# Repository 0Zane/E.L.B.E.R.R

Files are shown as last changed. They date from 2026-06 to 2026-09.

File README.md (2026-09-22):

<div align="center">
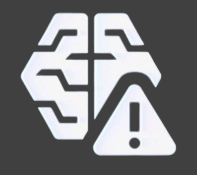
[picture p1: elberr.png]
E.L.B.E.R.R. icon
  

  <h1>E.L.B.E.R.R.</h1>

  <p>
    A fanmade animatronic robot powered by local AI, embedded control systems,
    and custom hardware.
  </p>

  <p>
    <a href="https://github.com/0Zane/E.L.B.E.R.R./stargazers">
      
    </a>
    <a href="https://github.com/0Zane/E.L.B.E.R.R./issues">
      
    </a>
    
    
    
    
  </p>
</div>

---

## Overview

**E.L.B.E.R.R.** is a fanmade animatronic project inspired by the robot featured
in the animations from [LIGHTS ARE OFF](https://www.youtube.com/@LIGHTSAREOFF).

The goal of this project is to recreate the character as a physical animatronic
robot using a custom local AI system, embedded motor control, sensors, and
purpose-built hardware. E.L.B.E.R.R. is designed as a self-contained robot that
can process information locally, control its own actuators, and respond through
real-time embedded systems.

> This is an unofficial fan project. It is not affiliated with, endorsed by, or
> produced by LIGHTS ARE OFF.

<div align="center">
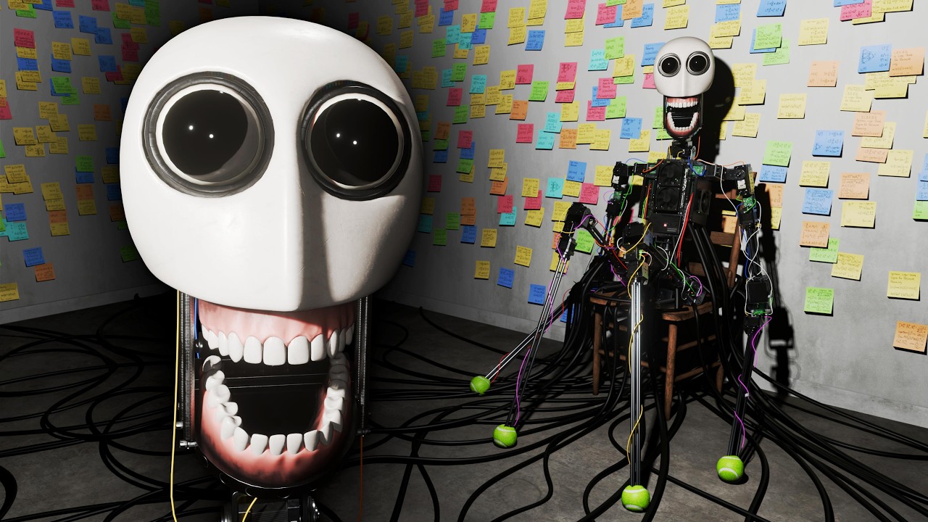
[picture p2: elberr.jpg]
E.L.B.E.R.R. animatronic reference
  
  <br />
  <sub>Reference image of the robot from the original animation.</sub>
</div>

---

## Built Robot Gallery

A few photos from the assembled robot, scaled for cleaner viewing in the repository.

<div align="center">
  <table>
    <tr>
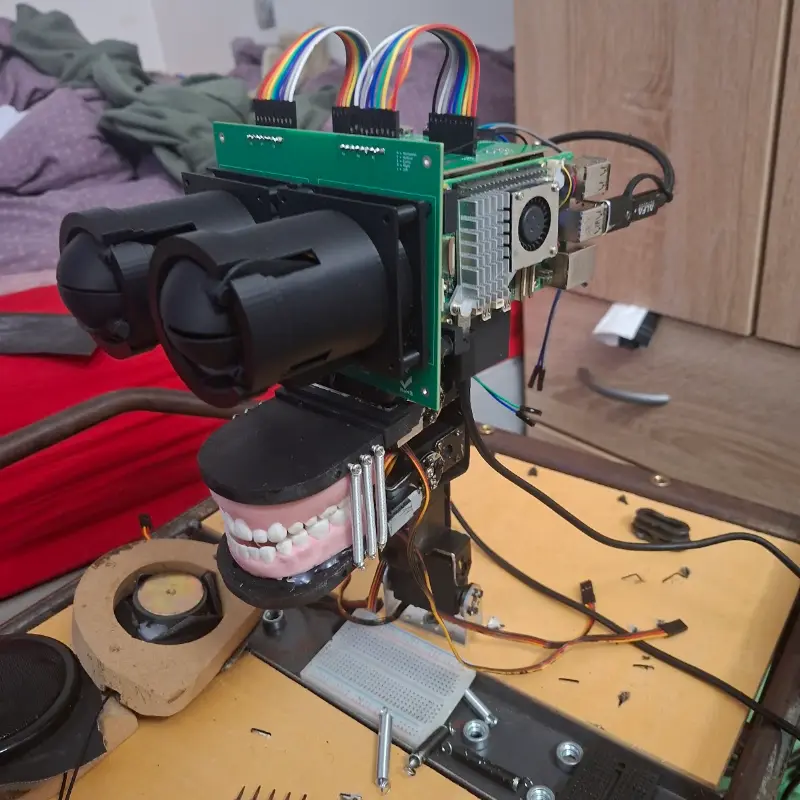
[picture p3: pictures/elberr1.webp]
E.L.B.E.R.R. assembled robot front view
      <td align="center"></td>
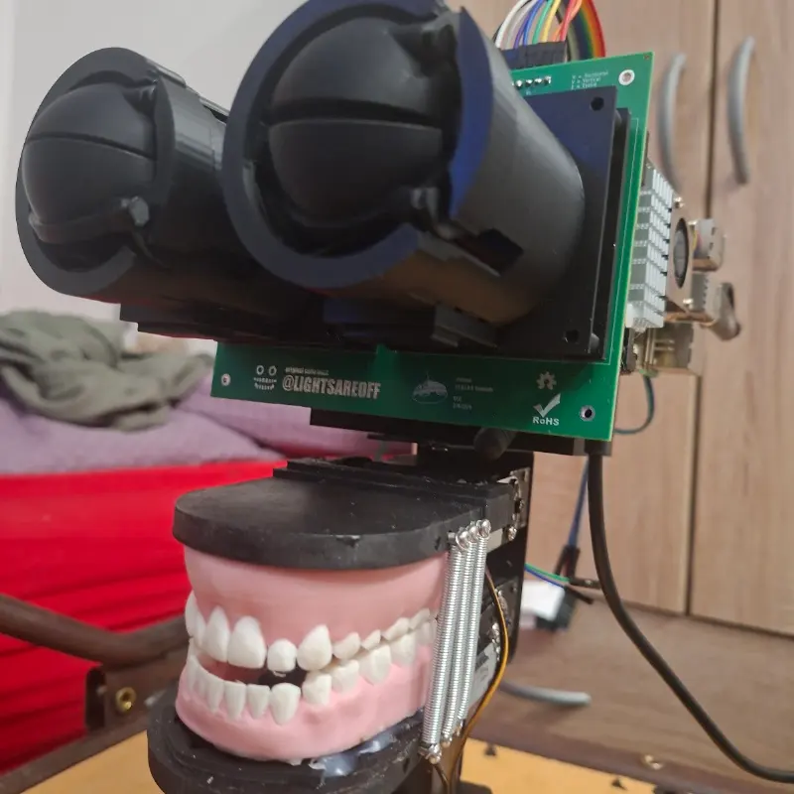
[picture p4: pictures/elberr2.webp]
E.L.B.E.R.R. assembled robot side view
      <td align="center"></td>
    </tr>
    <tr>
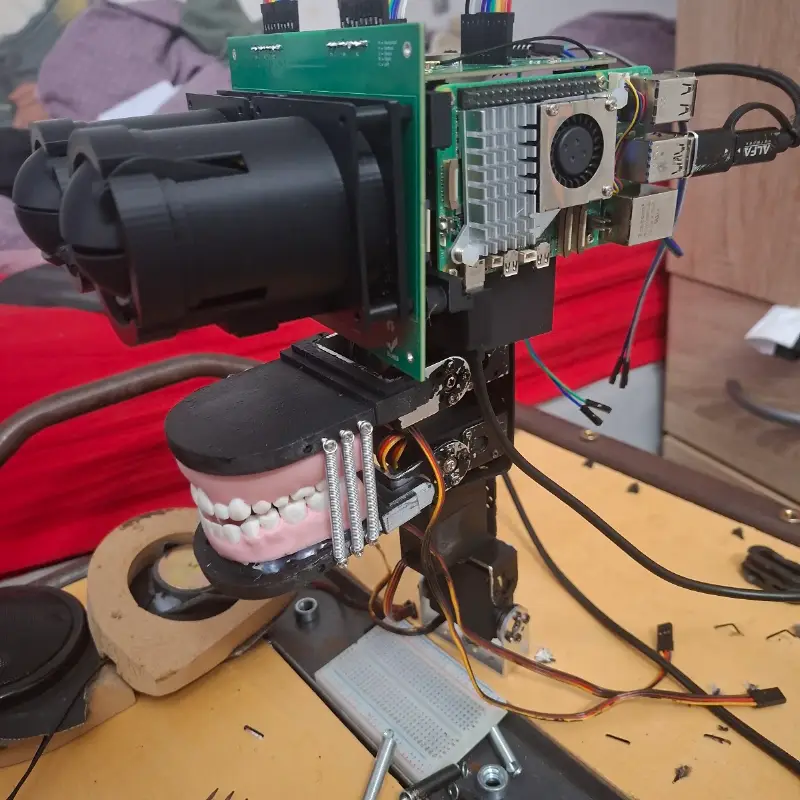
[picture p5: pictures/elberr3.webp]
E.L.B.E.R.R. assembled robot face detail
      <td align="center"></td>
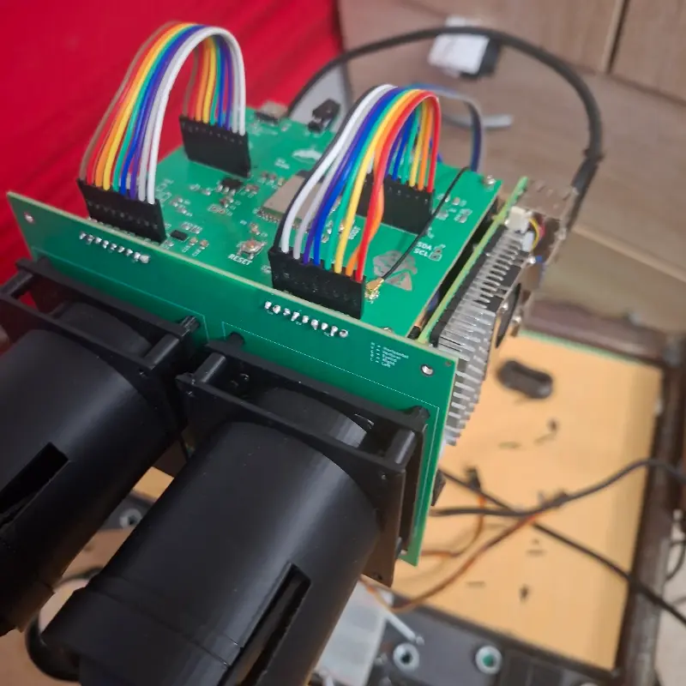
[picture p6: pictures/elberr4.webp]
E.L.B.E.R.R. assembled robot close-up
      <td align="center"></td>
    </tr>
  </table>
</div>

---

# Architecture

## Core Concept

E.L.B.E.R.R. is built around a three-processor architecture:

* A **Raspberry Pi 5** acts as the primary computer, running the local AI system, behavior engine, perception, and overall robot coordination.
* An **ESP32-S3** serves as the communication and sensing processor, handling environmental sensors, wireless connectivity, and RF communication.
* An **STM32** microcontroller is dedicated to real-time servo and actuator control, ensuring smooth, deterministic motion and reliable animatronic performance.

This separation allows each processor to focus on a specific task while keeping motion control isolated from higher-level software.

The Raspberry Pi 5, ESP32-S3, and STM32 communicate with one another over UART.

```mermaid
flowchart LR
  Camera[Camera] --> Pi[Raspberry Pi 5]
  Mic[Microphone] --> Pi
  Other[Embedded Sensors] --> ESP

  Pi <-->|UART| ESP[ESP32-S3]

  Pi --> AI[Local AI System]
  AI --> Behavior[Behavior Engine]

  Pi <-->|UART| STM[STM32]
  STM --> Servos[Servos]
  STM --> Actuators[Animatronic Actuators]
```

---

## Hardware Architecture

| Subsystem | Component | Purpose |
| --- | --- | --- |
| Main computer | Raspberry Pi 5 | Local AI, behavior logic, planning, vision processing, networking, and system orchestration |
| Sensor & RF controller | ESP32-S3 | Environmental sensors, wireless communication, RF capabilities, and data collection |
| Motion controller | STM32 | Real-time servo control, actuator control, deterministic timing, and motion safety |
| Mechanical system | Animatronic frame | Physical movement, expression, and character presence |
| Sensors | Cameras, microphones, IMUs, and embedded sensors | Environmental input and interaction data |
| PCB design | KiCad | Custom circuit design, wiring organization, and hardware integration |
| Firmware | C++ | Embedded software for STM32 and ESP32-S3 |

---

## Raspberry Pi 5

The Raspberry Pi 5 is the central computer of E.L.B.E.R.R.

Its responsibilities include:

* Running the local AI system
* Managing high-level robot behavior
* Processing camera, microphone, and perception data
* Coordinating communication between all processors
* Handling networking, logging, and debugging
* Making behavioral decisions before sending motion commands to the STM32

The Pi is responsible for what the robot **thinks**.

---

## ESP32-S3

The ESP32-S3 is dedicated to sensing and wireless communication.

Its responsibilities include:

* Reading environmental sensors
* Monitoring digital and analog inputs
* Handling RF and wireless communication
* Forwarding sensor information to the Raspberry Pi 5
* Providing low-power peripheral management

The ESP32-S3 is responsible for what the robot **perceives** and how it communicates with external devices.

---

## STM32

The STM32 is dedicated to real-time motion control.

Its responsibilities include:

* Driving servos and animatronic actuators
* Generating precise PWM outputs
* Executing smooth motion profiles
* Enforcing movement limits
* Monitoring actuator timing
* Executing commands received from the Raspberry Pi 5

The STM32 is responsible for how the robot **moves**.

---

## Hardware Schematics

The design files in the repository include the core hardware schematics and module layouts for the robot control system.

<div align="center">
  <table>
    <tr>
      <td align="center"><h3>ESP modules</h3>E.L.B.E.R.R. hardware module overview</td>
      <td align="center"><h3>ESP32-S3 board</h3>ESP32-S3 schematic</td>
      <td align="center"><h3>Eye module</h3>Eye module schematic</td>
    </tr>
  </table>
</div>

---

## Project Structure

```text
E.L.B.E.R.R/
|-- 3dmodels/
|-- esp32-firmware/
|   |-- include/
|   |-- lib/
|   |-- src/
|   |-- test/
|   `-- platformio.ini
|-- hardware/
|   |-- README.md
|   |-- esp/
|   |   |-- esp.kicad_pro
|   |   |-- esp.kicad_sch
|   |   |-- esp.kicad_pcb
|   |   |-- bom.csv
|   |   |-- production/
|   |   `-- esp-backups/
|   |-- eyes/
|   |   |-- eyes.kicad_pro
|   |   |-- eyes.kicad_sch
|   |   |-- eyes.kicad_pcb
|   |   |-- bom.csv
|   |   |-- production/
|   |   `-- eyes-backups/
|   |-- stm/
|   |   |-- stm.kicad_pro
|   |   |-- stm.kicad_sch
|   |   |-- stm.kicad_pcb
|   |   |-- stm-backups/
|   |   `-- ...
|   |-- esp.svg
|   |-- eyes.svg
|   `-- modules.svg
|-- pictures/
|   |-- elberr1.webp
|   |-- elberr2.webp
|   |-- elberr3.webp
|   `-- elberr4.webp
|-- software/
|   |-- README.md
|   |-- Modelfile
|   |-- boot.py
|   |-- llm.py
|   |-- main.py
|   |-- requirements.txt
|   |-- stt.py
|   |-- tts.py
|   `-- memory/
|-- stm32-firmware/
|   |-- Core/
|   |-- Drivers/
|   |-- EWARM/
|   |-- stm32-firmware.ioc
|   `-- ...
|-- index.html
|-- elberr.jpg
|-- elberr.png
|-- README.md
|-- LICENSE
`-- .gitignore (if present)
```

---

## Technologies

| Area | Technology |
| --- | --- |
| Main compute | Raspberry Pi 5 |
| Sensor processor  | ESP32-S3 |
| Motion controller | STM32 |
| Firmware | C++ |
| PCB design | KiCad |
| 3D modeling | Fusion 360 |
| AI | Local custom AI system |
| Architecture | Distributed embedded system |

---

## Inspiration

This project is inspired by the robot created in the animations from
[LIGHTS ARE OFF](https://www.youtube.com/@LIGHTSAREOFF).

E.L.B.E.R.R. is a fanmade physical interpretation of that concept, built as a
personal robotics, AI, and embedded systems project.

---

## License

This project is licensed under the **MIT License**.

See the [LICENSE](./LICENSE) file for details.

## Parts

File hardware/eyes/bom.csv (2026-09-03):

Reference | Qty | Value | DNP | Exclude from BOM | Exclude from Board | Footprint | Datasheet
C1,C2 | 2 | 0.1uF |  |  |  | Capacitor_SMD:C_0805_2012Metric
C7 | 1 | 100uF |  |  |  | Capacitor_THT:CP_Radial_D8.0mm_P3.50mm
J1,J2,J3,J4 | 4 | Conn_01x09_Pin |  |  |  | Connector_PinHeader_2.54mm:PinHeader_1x09_P2.54mm_Vertical
J5 | 1 | Barrel_Jack |  |  |  | Connector_BarrelJack:BarrelJack_Horizontal
J8,J9 | 2 | Conn_01x22 |  |  |  | Connector_FFC-FPC:Amphenol_F32Q-1A7x1-11022_1x22-1MP_P0.5mm_Horizontal

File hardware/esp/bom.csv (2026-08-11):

Reference | Value | Footprint | Qty | DNP
C1,C3,C7,C9 | 10uF | Capacitor_SMD:C_0805_2012Metric | 4
C2,C4,C6,C10,C15,C23,C24,C25 | 0.1uF | Capacitor_SMD:C_0805_2012Metric | 8
C5,C11,C18 | 4.7uF | Capacitor_SMD:C_0805_2012Metric | 3
C8 | 0.1µF | Capacitor_SMD:C_0805_2012Metric | 1
C12 | 10nF | Capacitor_SMD:C_0603_1608Metric | 1
C13 | 1nF | Capacitor_SMD:C_0603_1608Metric | 1
C14 | 33nF | Capacitor_SMD:C_0603_1608Metric | 1
C16,C19 | 22pF | Capacitor_SMD:C_0603_1608Metric | 2
C17 | 2.2nF | Capacitor_SMD:C_0805_2012Metric | 1
C20 | 4.7pF | Capacitor_SMD:C_0805_2012Metric | 1
C21 | 1.5pF | Capacitor_SMD:C_0603_1608Metric | 1
C22 | 1pF | Capacitor_SMD:C_0603_1608Metric | 1
D1,D2,D3,D10,D11,D12 | D_TVS | Diode_SMD:D_SOD-123 | 6
D4,D5,D6,D7,D8,D9 | LED | LED_SMD:LED_0603_1608Metric | 6
J1,J4,J9 | Conn_01x02 | Connector_PinHeader_2.54mm:PinHeader_1x02_P2.54mm_Vertical | 3
J2,J3 | USB_C_Receptacle_USB2.0_16P | Connector_USB:USB_C_Receptacle_HCTL_HC-TYPE-C-16P-01A | 2
J5 | Conn_Coaxial | Connector_Coaxial:U.FL_Molex_MCRF_73412-0110_Vertical | 1
J6,J8 | Conn_01x09_Pin | Connector_PinHeader_2.54mm:PinHeader_1x09_P2.54mm_Vertical | 2
J7 | Conn_01x06_Pin | Connector_PinHeader_2.54mm:PinHeader_1x06_P2.54mm_Vertical | 1
L1 | 8.2nH | Inductor_SMD:L_0603_1608Metric | 1
L2 | 3.9nH | Inductor_SMD:L_0603_1608Metric | 1
L3 | 2.7nH | Inductor_SMD:L_0603_1608Metric | 1
R1,R2,R5,R6 | 5.1k | Resistor_SMD:R_0805_2012Metric | 4
R3,R4 | 22R | Resistor_SMD:R_0805_2012Metric | 2
R7,R8,R11,R12,R13,R14,R19 | 1k | Resistor_SMD:R_0805_2012Metric | 7
R9,R24 | 10k | Resistor_SMD:R_0805_2012Metric | 2
R10 | 10K | Resistor_SMD:R_0805_2012Metric | 1
R15,R16,R20,R21 | 4.7k | Resistor_SMD:R_0805_2012Metric | 4
R17 | 22K | Resistor_SMD:R_0603_1608Metric | 1
R18 | 1M | Resistor_SMD:R_0805_2012Metric | 1
R22 | 47.5k | Resistor_SMD:R_0805_2012Metric | 1
R23 | 22.1k | Resistor_SMD:R_0805_2012Metric | 1
SW1 | RESET | Button_Switch_SMD:SW_SPST_SKQG_WithStem | 1
SW2 | BOOT | Button_Switch_SMD:SW_SPST_SKQG_WithStem | 1
U1 | AMS1117-3.3 | Package_TO_SOT_SMD:SOT-223-3_TabPin2 | 1
U2 | CP2102N-Axx-xQFN20 | Package_DFN_QFN:SiliconLabs_QFN-20-1EP_3x3mm_P0.5mm_EP1.8x1.8mm | 1
U3 | ESP32-S3-WROOM-1 | RF_Module:ESP32-S3-WROOM-1 | 1
U4 | VL53L0X | VL53L0X:SENSOR_VL53L0X | 1
U5 | NRF24L01 | Package_DFN_QFN:QFN-20-1EP_4x4mm_P0.5mm_EP2.5x2.5mm | 1
U6 | BME280 | Package_LGA:Bosch_LGA-8_2.5x2.5mm_P0.65mm_ClockwisePinNumbering | 1
Y1 | 16MHz | Crystal:Crystal_SMD_3225-4Pin_3.2x2.5mm | 1

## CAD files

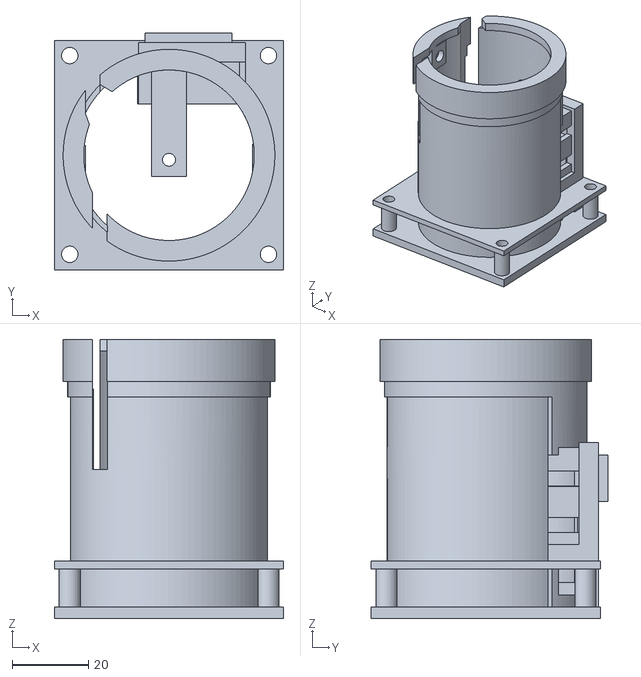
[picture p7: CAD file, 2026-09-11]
3dmodels/eyesupport.stl
60.0 x 62.0 x 73.0

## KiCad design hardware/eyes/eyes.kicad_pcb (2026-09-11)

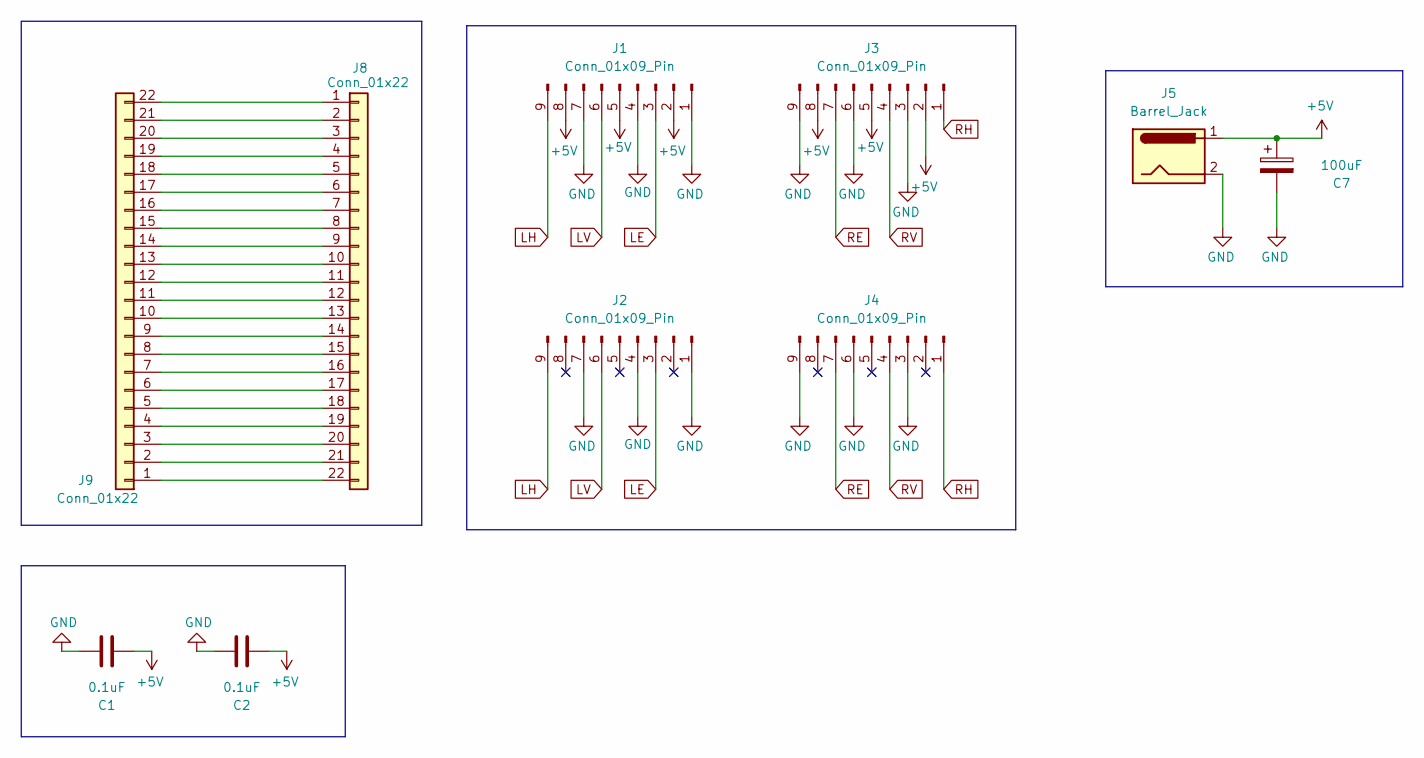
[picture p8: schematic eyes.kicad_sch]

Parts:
C1, C2: 0.1uF; C_0805_2012Metric
C7: 100uF; CP_Radial_D8.0mm_P3.50mm
J1, J2, J3, J4: Conn_01x09_Pin; PinHeader_1x09_P2.54mm_Vertical
J5: Barrel_Jack; BarrelJack_Horizontal
J8, J9: Conn_01x22; Amphenol_F32Q-1A7x1-11022_1x22-1MP_P0.5mm_Horizontal

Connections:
+5V: C1.1, C2.1, C7.1, J1.2, J1.5, J1.8, J3.2, J3.5, J3.8, J5.1
GND: C1.2, C2.2, C7.2, J1.1, J1.4, J1.7, J2.1, J2.4, J2.7, J3.3, J3.6, J3.9, J4.3, J4.6, J4.9, J5.2
LE: J1.3, J2.3
LH: J1.9, J2.9
LV: J1.6, J2.6
unnamed: J8.1, J9.22
unnamed: J8.2, J9.21
unnamed: J8.3, J9.20
unnamed: J8.4, J9.19
unnamed: J8.5, J9.18
unnamed: J8.6, J9.17
unnamed: J8.7, J9.16
unnamed: J8.8, J9.15
unnamed: J8.9, J9.14
unnamed: J8.10, J9.13
unnamed: J8.11, J9.12
unnamed: J8.12, J9.11
unnamed: J8.13, J9.10
unnamed: J8.14, J9.9
unnamed: J8.15, J9.8
unnamed: J8.16, J9.7
unnamed: J8.17, J9.6
unnamed: J8.18, J9.5
unnamed: J8.19, J9.4
unnamed: J8.20, J9.3
unnamed: J8.21, J9.2
unnamed: J8.22, J9.1
RE: J3.7, J4.7
RH: J3.1, J4.1
RV: J3.4, J4.4

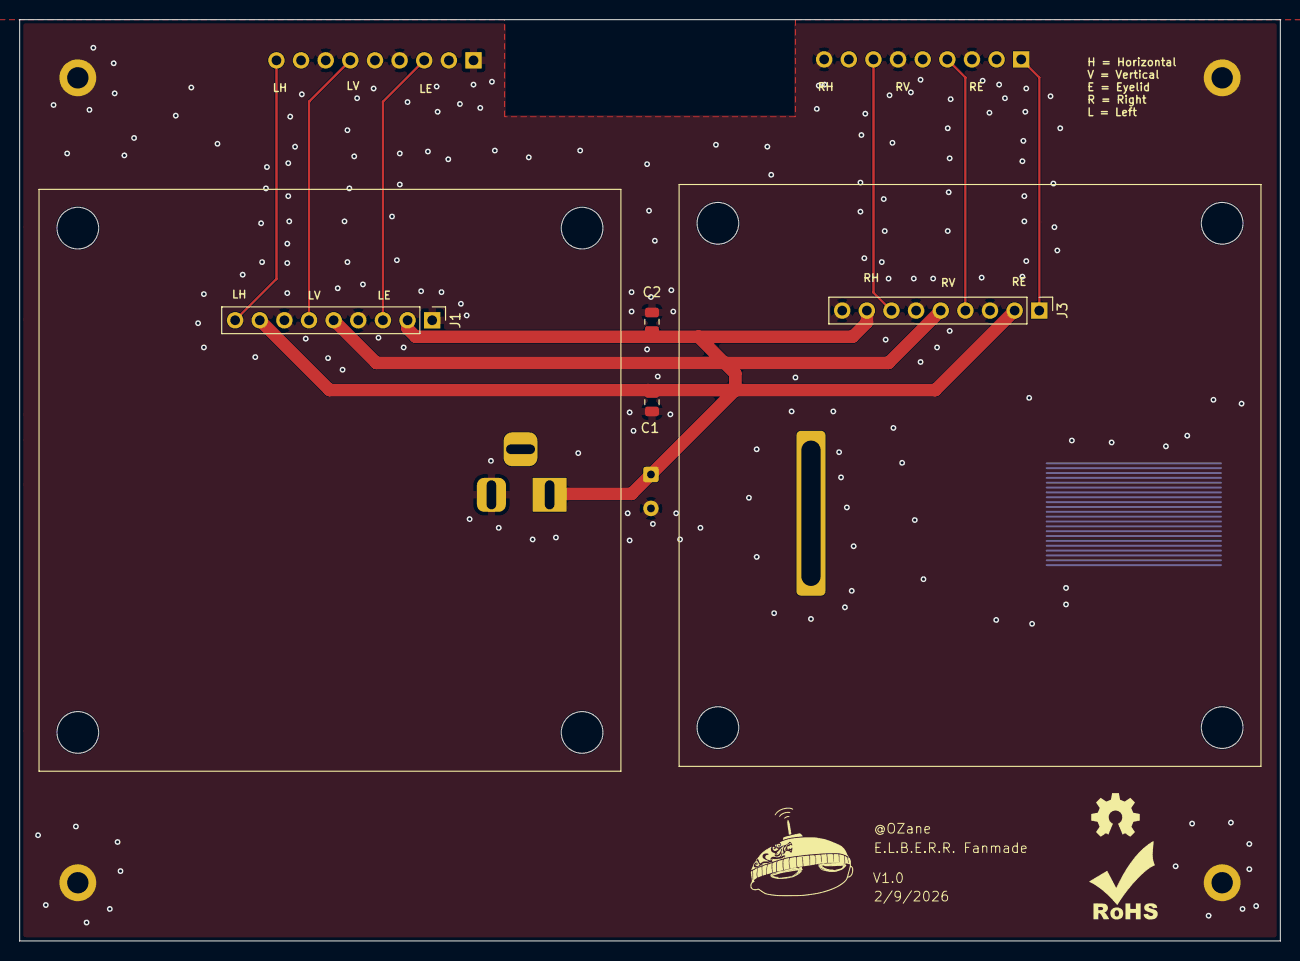
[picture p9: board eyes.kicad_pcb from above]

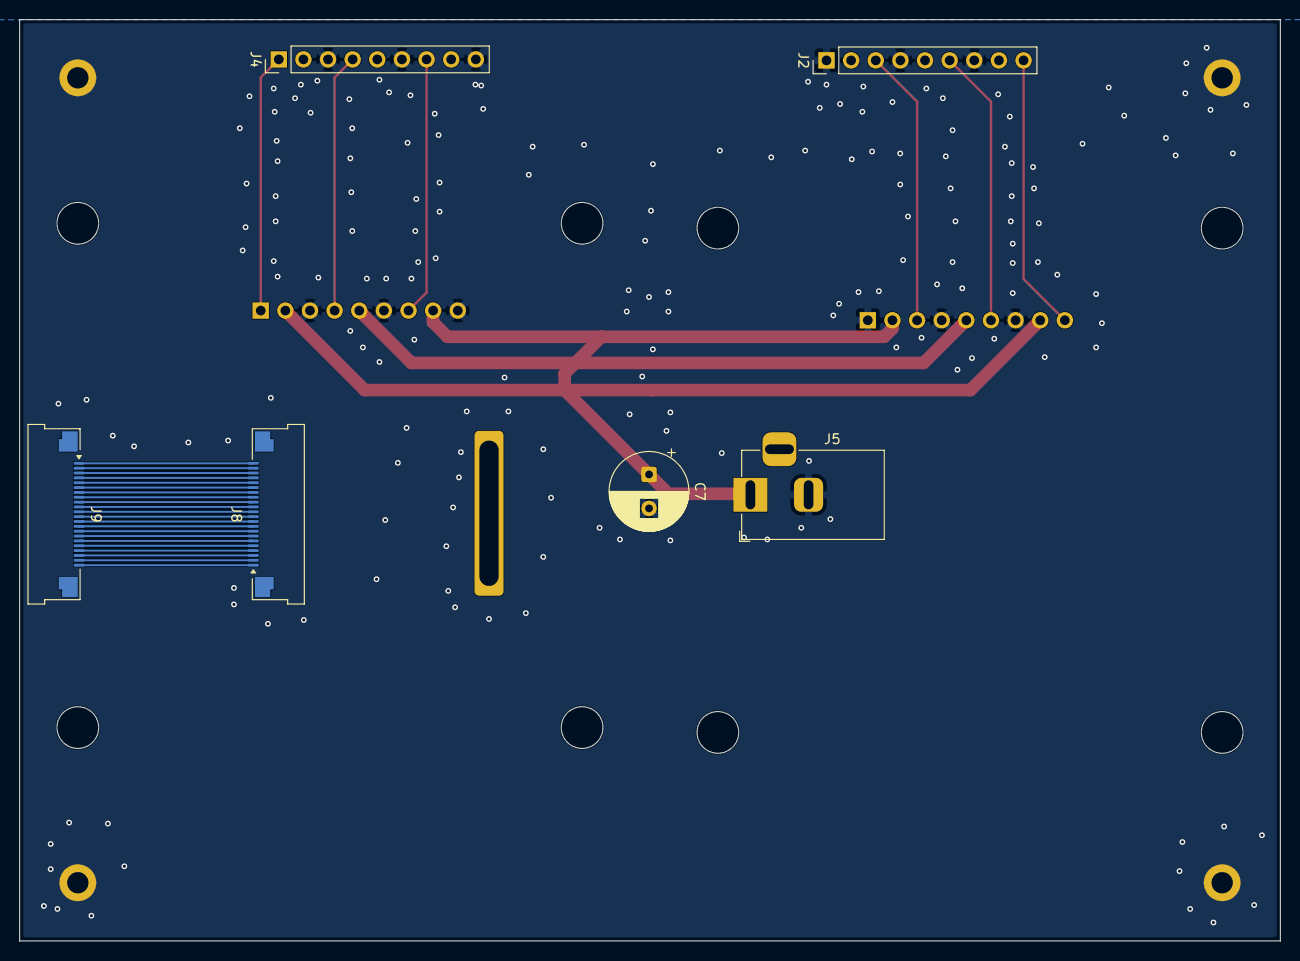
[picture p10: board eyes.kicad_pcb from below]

Board: 2 copper layers, 130.0 x 95.0 mm, 10 parts (6 on the bottom side), 30 nets.

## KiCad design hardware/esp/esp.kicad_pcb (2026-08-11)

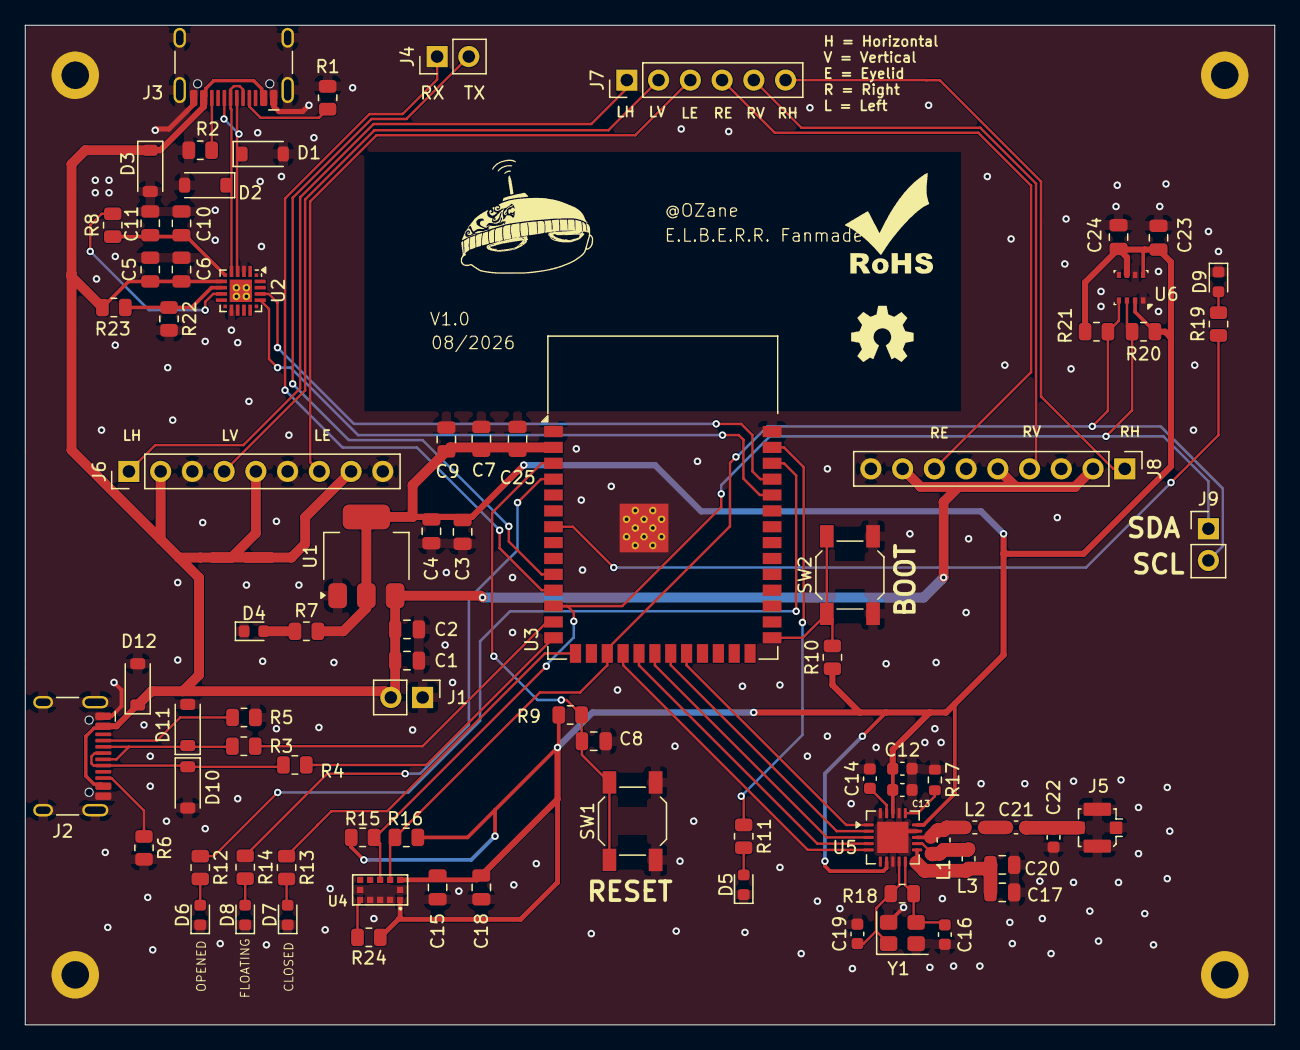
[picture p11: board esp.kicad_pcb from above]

Board: 2 copper layers, 100.0 x 80.0 mm, 82 parts (0 on the bottom side), 56 nets.

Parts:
C1, C3, C7, C9: 10uF; C_0805_2012Metric
C2, C4, C6, C10, C15, C23, C24, C25: 0.1uF; C_0805_2012Metric
C5, C11, C18: 4.7uF; C_0805_2012Metric
C8: 0.1µF; C_0805_2012Metric
C12: 10nF; C_0603_1608Metric
C13: 1nF; C_0603_1608Metric
C14: 33nF; C_0603_1608Metric
C16, C19: 22pF; C_0603_1608Metric
C17: 2.2nF; C_0805_2012Metric
C20: 4.7pF; C_0805_2012Metric
C21: 1.5pF; C_0603_1608Metric
C22: 1pF; C_0603_1608Metric
D1, D2, D3, D10, D11, D12: D_TVS; D_SOD-123
D4, D5, D6, D7, D8, D9: LED; LED_0603_1608Metric
J1, J4, J9: Conn_01x02; PinHeader_1x02_P2.54mm_Vertical
J2, J3: USB_C_Receptacle_USB2.0_16P; USB_C_Receptacle_HCTL_HC-TYPE-C-16P-01A
J5: Conn_Coaxial; U.FL_Molex_MCRF_73412-0110_Vertical
J6, J8: Conn_01x09_Pin; PinHeader_1x09_P2.54mm_Vertical
J7: Conn_01x06_Pin; PinHeader_1x06_P2.54mm_Vertical
L1: 8.2nH; L_0603_1608Metric
L2: 3.9nH; L_0603_1608Metric
L3: 2.7nH; L_0603_1608Metric
R1, R2, R5, R6: 5.1k; R_0805_2012Metric
R3, R4: 22R; R_0805_2012Metric
R7, R8, R11, R12, R13, R14, R19: 1k; R_0805_2012Metric
R9, R24: 10k; R_0805_2012Metric
R10: 10K; R_0805_2012Metric
R15, R16, R20, R21: 4.7k; R_0805_2012Metric
R17: 22K; R_0603_1608Metric
R18: 1M; R_0805_2012Metric
R22: 47.5k; R_0805_2012Metric
R23: 22.1k; R_0805_2012Metric
SW1: RESET; SW_SPST_SKQG_WithStem
SW2: BOOT; SW_SPST_SKQG_WithStem
U1: AMS1117-3.3; SOT-223-3_TabPin2
U2: CP2102N-Axx-xQFN20; SiliconLabs_QFN-20-1EP_3x3mm_P0.5mm_EP1.8x1.8mm
U3: ESP32-S3-WROOM-1
U4: VL53L0X; SENSOR_VL53L0X
U5: NRF24L01; QFN-20-1EP_4x4mm_P0.5mm_EP2.5x2.5mm
U6: BME280; Bosch_LGA-8_2.5x2.5mm_P0.65mm_ClockwisePinNumbering
Y1: 16MHz; Crystal_SMD_3225-4Pin_3.2x2.5mm

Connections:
+3V3: C3.1, C4.1, C7.2, C9.2, C12.2, C13.2, C15.1, C18.1, C23.2, C24.2, C25.2, R7.2, R9.2, R10.1, R15.1, R16.1, R20.2, R21.2, R24.1, U1.2 (VO), U3.2 (3V3), U4.1 (AVDDVCSEL), U4.11 (AVDD), U5.7 (VDD), U5.15 (VDD), U5.18 (VDD), U6.2 (CSB), U6.6 (VDDIO), U6.8 (VDD)
+5V: C1.1, C2.1, C5.1, C6.1, D3.1 (A1), D12.1 (A1), J1.2, J2.A4 (VBUS), J2.A9 (VBUS), J2.B4 (VBUS), J2.B9 (VBUS), J3.A4 (VBUS), J3.A9 (VBUS), J3.B4 (VBUS), J3.B9 (VBUS), J6.2, J6.5, J6.8, J8.2, J8.5, J8.8, R23.1, U1.3 (VI), U2.7 (VREGIN)
/VDD: C10.1, C11.1, R8.1, U2.6 (VDD)
BOOT: R10.2, SW2.1, U3.27 (IO0)
C.SKULL: R13.1, U3.15 (IO3)
D+: R4.2, U3.14 (USB_D+)
D-: R3.2, U3.13 (USB_D-)
EN: C8.2, R9.1, SW1.1, U3.3 (EN)
GND: C1.2, C2.2, C3.2, C4.2, C5.2, C6.2, C7.1, C8.1, C9.1, C10.2, C11.2, C12.1, C13.1, C14.2, C15.2, C16.1, C17.2, C18.2, C19.2, C20.2, C22.1, C23.1, C24.1, C25.1, D1.2 (A2), D2.2 (A2), D3.2 (A2), D4.1 (K), D5.1 (K), D6.1 (K), D7.1 (K), D8.1 (K), D9.1 (K), D10.2 (A2), D11.2 (A2), D12.2 (A2), J1.1, J2.A1 (GND), J2.A12 (GND), J2.B1 (GND), J2.B12 (GND), J2.SH (SHIELD), J3.A1 (GND), J3.A12 (GND), J3.B1 (GND), J3.B12 (GND), J3.SH (SHIELD), J5.2 (Ext), J6.3, J6.6, J6.9, J8.3, J8.6, J8.9, R1.2, R2.2, R5.2, R6.2, R17.1, R22.2, SW1.2, SW2.2, U1.1 (GND), U2.3 (GND), U2.12 (GND), U2.21 (GND), U3.1 (GND), U3.40 (GND), U3.41 (GND), U4.2 (AVSSVCSEL), U4.3 (GND), U4.4 (GND), U4.6 (GND), U4.12 (GND), U5.8 (VSS), U5.14 (VSS), U5.17 (VSS), U5.20 (VSS), U5.21 (VSS), U6.1 (GND), U6.7 (GND), Y1.2 (G), Y1.4 (G)
LE: J6.7, J7.3
LH: J6.1, J7.1
LV: J6.4, J7.2
MISO: U3.18 (IO10), U5.5 (MISO)
MOSI: U3.19 (IO11), U5.4 (MOSI)
NF.SKULL: R14.1, U3.4 (IO4)
NRFLED: R11.1, U3.39 (IO1)
NRF_CE: U3.22 (IO14), U5.1 (CE)
NRF_CSN: U3.21 (IO13), U5.2 (CSN)
unnamed: C21.1, L2.2
unnamed: D1.1 (A1), J3.A6 (D+), J3.B6 (D+), U2.4 (D+)
unnamed: D2.1 (A1), J3.A7 (D-), J3.B7 (D-), U2.5 (D-)
unnamed: D4.2 (A), R7.1
unnamed: D5.2 (A), R11.2
unnamed: D6.2 (A), R12.2
unnamed: D7.2 (A), R13.2
unnamed: D8.2 (A), R14.2
unnamed: D9.2 (A), R19.2
unnamed: D10.1 (A1), J2.A6 (D+), J2.B6 (D+), R4.1
unnamed: D11.1 (A1), J2.A7 (D-), J2.B7 (D-), R3.1
unnamed: J2.A5 (CC1), R5.1
unnamed: J2.B5 (CC2), R6.1
unnamed: J3.A5 (CC1), R1.1
unnamed: J3.B5 (CC2), R2.1
unnamed: C21.2, C22.2, J5.1 (In)
unnamed: R22.1, R23.2, U2.8 (VBUS)
unnamed: R8.2, U2.9 (~RST)
unnamed: R24.2, U4.5 (~XSHUT)
unnamed: L1.2, L3.1, U5.12 (ANT1)
unnamed: L1.1, L2.1, U5.13 (ANT2)
unnamed: C14.1, U5.19 (DVDD)
unnamed: R17.2, U5.16 (IREF)
unnamed: C17.1, C20.1, L3.2, U5.11 (VDD_PA)
unnamed: C16.2, R18.1, U5.10 (XC1), Y1.3
unnamed: C19.1, R18.2, U5.9 (XC2), Y1.1
O.SKULL: R12.1, U3.38 (IO2)
RE: J7.4, J8.7
RH: J7.6, J8.1
RV: J7.5, J8.4
RX: U2.18 (TXD), U3.37 (TXD0)
RX2: J4.1, U3.11 (IO18)
SCK: U3.20 (IO12), U5.3 (SCK)
SCL: J9.2, R16.2, R21.1, U3.17 (IO9), U4.10 (SCL), U6.4 (SCK)
SDA: J9.1, R15.2, R20.1, U3.12 (IO8), U4.9 (SDA), U6.3 (SDI)
TEMP_LED: R19.1, U3.7 (IO7)
TX: U2.17 (RXD), U3.36 (RXD0)
TX2: J4.2, U3.10 (IO17)

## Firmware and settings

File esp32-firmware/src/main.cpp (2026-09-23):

//Include system libraries
#include <Arduino.h>
#include <Wire.h>
#include <string>
//Include custom header files
#include "pins.h"
#include "body.h"
#include "temperature.h"
#include "nrf24.h"
#include "wififeatures.h"
#include "led.h"

string receivedMessage = "";

void setup() {


  Serial.begin(9600);

  /*
  Wire.begin(I2C_SDA, I2C_SCL);
  Wire.setClock(400000L);

  if (!initBME280()) {
    Serial.println("BME280 did not start.");
  }

  Serial.println("Starting VL53L0X...");
  if (!lox.begin()) {
    Serial.println("VL53L0X did not respond.");
  } else {
    lox.startRangeContinuous();
    delay(100);
    Serial.println("VL53L0X started.");
  }
    */

  ledOn(NRFLED);
  ledOn(OSKULLLED);
  ledOn(CSKULLLED);
  ledOn(NFSKULLLED);
  ledOn(TEMPLED);



}

void loop() {
  Serial.print("Hello");
  delay(1000);
}

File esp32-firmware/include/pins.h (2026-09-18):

//I2C BUS 
#define I2C_SCL 9
#define I2C_SDA 8

//SPI BUS
#define SPI_MOSI 11
#define SPI_MISO 10
#define SPI_SCK 12
#define NRF_CSN 13
#define NRF_CE 14

//UART WITH RASPBERRY PI
#define UART1_RX_PIN 17
#define  UART1_TX_PIN 18

//LED
#define NRFLED 1
#define OSKULLLED 2
#define CSKULLLED 3
#define NFSKULLLED 4
#define TEMPLED 7

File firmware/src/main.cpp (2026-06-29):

#include <Arduino.h>
//include libraries for bme280, ble modules, and other modules not related with servos

void setup() {
  //initialize UART communication with rp5
  //initialize communications with modules
}

void loop() {
  //listen to UART from rp5 and send information (maybe direct regular push)
}

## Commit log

2026-06-23 Adding pcb files
    [mcu.kicad_pcb, mcu.kicad_sch]
2026-06-23 Recreating kicad project after path problem
    [mcu_board.kicad_pcb, mcu_board.kicad_sch]
2026-06-26 PCB first commits
    [mcu_board.kicad_pcb, mcu_board.kicad_sch]
2026-06-28 Adding ESP PCB files
    [esp.kicad_pcb, esp.kicad_sch]
2026-06-30 Relocalizing firmware dedicated to est32 in a dedicated folder, Creating new header files and cleaning old servo motor control code.
2026-07-10 Adding temperature cpp files and code
2026-07-11 Programming the distance sensor to determine if the skull is opened
2026-07-11 Updating PCB
    [esp.kicad_pcb, esp.kicad_sch]
2026-07-12 Updating schematics
    [esp.kicad_sch]
2026-07-12 Updating PCb and esp board schematics
    [esp.kicad_pcb, esp.kicad_sch]
2026-07-13 Fixing header files declaration
    [main.cpp]
2026-07-14 Fixing temperature reading
2026-07-15 Updating schematics and PCB
    [esp.kicad_pcb, esp.kicad_sch, modules.kicad_sch]
2026-07-15 updating gitignore for PCB files
2026-07-17 Updating pins, working on schematic and placing components on PCB
    [esp.kicad_pcb, esp.kicad_sch, modules.kicad_sch]
2026-07-18 Updating schematics and PCB layout
    [esp.kicad_pcb, esp.kicad_sch, modules.kicad_sch]
2026-07-19 Initializint UART communication between Raspberry pi 5 and ESP32
2026-07-20 Removing UART LEDs
    [esp.kicad_pcb, esp.kicad_sch]
2026-07-21 Placing components on PCB and starting routing
    [esp.kicad_pcb, esp.kicad_sch, modules.kicad_sch]
2026-07-22 Placing Bidirectional TVS diodes and fixing schematic + placing components on pcb
    [esp.kicad_pcb, esp.kicad_sch, modules.kicad_sch]
2026-07-23 adding bom
    [bom.csv]
2026-07-24 Updating pins, and scehmatic
    [esp.kicad_pcb, esp.kicad_sch, modules.kicad_sch]
2026-07-25 Fixing schematic error and routing PCB
    [esp.kicad_pcb, esp.kicad_sch, modules.kicad_sch]
2026-07-28 creating uart.cpp file that manages the serial communication with the raspberry pi 5
2026-07-29 Modifiying schematic after schematic review
    [esp.kicad_pcb, esp.kicad_sch, modules.kicad_sch]
2026-08-05 Updating project BOM
    [bom.csv]
2026-08-05 Updating schemaitc, and component placement on PCB
    [esp.kicad_pcb, esp.kicad_sch, modules.kicad_sch]
2026-08-05 Updating schematic, BOM, and component placement on PCB
    [bom.csv, esp.kicad_pcb, esp.kicad_sch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]
2026-08-07 Starting PCB routing, updating schematic pins and firmware pins for optimal routing
    [esp.kicad_pcb, esp.kicad_sch, modules.kicad_sch]
2026-08-07 Finishing PCB routing (PRE-DRC)
    [esp.kicad_pcb, esp.kicad_sch]
2026-08-07 Placing mounting holes, routing impedance matching drace
    [esp.kicad_pcb, modules.kicad_sch]
2026-08-11 Updating BOM, adding fixes to the PCB and silkscreen finishes
    [bom.csv, esp.kicad_pcb, esp.kicad_sch]
2026-08-13 Adding STM32 PCB project
    [stm.kicad_pcb, stm.kicad_sch]
2026-08-14 Programming AI flow
2026-08-18 Fixing all bugs in the firmware causing compilation error
    [main.cpp, uart.cpp]
2026-08-23 Adding LED control
2026-08-25 Adding 3rd PCB files
    [eyes.kicad_pcb, eyes.kicad_sch]
2026-09-02 Updating project organization and ignored files
    [mcu_board.kicad_pcb, mcu_board.kicad_sch]
2026-09-02 Finishing eyes board schematics, and PCB
    [eyes.kicad_pcb, eyes.kicad_sch]
2026-09-02 general fixes
    [modules.kicad_sch]
2026-09-03 Recovering kicad files
    [eyes.kicad_sch]
2026-09-03 Finishing eyes PCB and exporting BOM
    [bom.csv, eyes.kicad_pcb, eyes.kicad_sch]
2026-09-11 Adding 3d file & modifying detail on PCB
    [eyes.kicad_pcb, eyesupport.stl]
2026-09-18 Fixing esp32 firmware bugs (mainly syntax errors or definition errors)
    [main.cpp, pins.h]
2026-09-22 Updating documentation with up to date hardware schematics and pictures
2026-09-23 Optimizing code for LED control
2026-10-02 Adding UART communication software feature
2026-10-02 Adapting the firmware to UART communcation with raspberry pi
2026-10-17 Creating STM32 project
2026-10-18 Fixing big problem a project creation and successfully blinking LED
2026-10-20 Configuring system clock and Programming PWM signals
2026-10-21 Working on STM32 schematic
2026-10-21 Configuring new Timer and channels for PWM and starting UART code

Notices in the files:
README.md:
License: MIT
